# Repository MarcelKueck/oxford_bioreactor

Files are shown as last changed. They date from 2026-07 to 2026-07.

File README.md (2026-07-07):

# oxford_bioreactor

Parametric CAD for the soft hollow-fibre bioreactor chamber.

## `fusion360/end_piece_and_ring.py`

Builds one rigid **end piece** + its **tightening ring** (both Formlabs SLA, biocompatible
resin). The two chamber ends are geometrically identical, so this single part serves both —
print two end pieces and two rings.

**How to run**
1. In Fusion 360 open a new/empty **Design**, then **Utilities → Scripts and Add-Ins → Scripts → Create** a Python script and replace its `*.py` with `end_piece_and_ring.py` (or point the script folder at `fusion360/`).
2. Select it and click **Run**. It builds two components (`EndPiece`, `TighteningRing`) in the active document and pops a summary; nothing is saved or exported. Re-running is safe — it deletes and rebuilds the two components.
3. **Tweak first:** `shell_bore` (bore for the fibre bundle + potting) and `spigot_OD` (must match your silicone cuff ID); edit them under **Modify → Change Parameters** or at the top of the script, then Run again. Set `USE_LUER = False` near the top for hose barbs (`tubing_id`) instead of female Luer ports.

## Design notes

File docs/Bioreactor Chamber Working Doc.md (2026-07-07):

# Soft Hollow-Fibre Bioreactor Chamber — Project Working Document

*Personal reference and working log. Created 26 June 2026.*
*This is a living document — update the checklists, logs, and KPIs as the project moves and as numbers get locked down.*

---

## 0. How to use this

This is my single source of truth for the internship: what I'm building, why, what's been tried already, what the targets are, and what I still need to find out. Sections 1–2 are context I can re-read or lift when explaining the project. Sections 3–9 are the working core. Sections 10–12 are checklists and logs I tick off and add to as I go.

The one structural idea to keep in mind: **everything is organised around two feedback loops** (chamber design, then fibre potting), and a feedback loop is only real if the test half produces a repeatable *number*. So my first job isn't a chamber redesign — it's building the test rig that makes redesigns comparable.

---

## 1. Project at a glance

**What the project is.** I'm contributing to Marie Kruth's DPhil (NDORMS, supervised by Prof. Pierre-Alexis Mouthuy, with Profs. Philippa Hulley and Hua Ye). The DPhil is building a human *in vitro* skeletal-muscle model to reduce reliance on animal models — most drugs that work in animals fail in human trials, so there's a real need for human-relevant muscle tissue for drug testing and disease study.

**The three-part DPhil plan, and where I fit:**

1. *Electrospun hollow-fibre (eHF) scaffold* — mostly done (dissolvable collector, electrospinning, stretch-alignment). This is Marie's completed work.
2. **Soft flexible bioreactor chamber** — **this is my piece.** The chamber houses the fibre bundle, perfuses it (artificial vasculature, beating the ~100–200 µm diffusion limit), and transmits mechanical stretch to the growing tissue.
3. *Muscle culture + drug response* — downstream, depends on a working chamber.

**Why "soft."** Muscle needs cyclic mechanical loading to mature. So the chamber can't be a rigid cartridge — it has to flex to pass stretch from an external mechanical platform to the fibres, while still perfusing them.

**People & roles**
- *Marie Kruth* — supervisor, owns the DPhil, my main point of contact and the source of most of the numbers I still need.
- *Prof. Mouthuy* — PI; his group also built the humanoid bioreactor platform (Mouthuy et al., 2022, *Comms Eng*) that's a candidate mechanical-loading system.
- *Profs. Hulley & Ye* — co-supervisors.

**Timeline note.** The project proposal labels the build as Aug–Sept 2026, but I'm starting now (late June). That's actually ideal: **June–July is the natural window to build the test rigs and lock down the missing numbers**, so that when the core build phase hits I'm iterating against real, quantitative targets instead of figuring out how to measure things.

**Toolchain:** Fusion 360 (CAD) → SLA 3D printing (clear medical-grade resin) → soft membrane bonded on (Permali Tuftane TPU film, Stormsure polyurethane glue).

---

## 2. What I'm building

### The inherited starting point (one option, not a requirement)
The design I'm inheriting: two rigid SLA-printed end-pieces ("top and bottom") connected by a flexible TPU membrane sleeve in the middle. Medium perfuses through; the membrane flexes to transmit stretch; the fibre bundle runs down the axis, potted into the printed pieces at each end. **This is a valid starting point, not a constraint** — see "Architecture: what's fixed vs what's mine to decide" below.

### Current design state (from my Fusion file)
The model shows the two printed pieces. Each has:
- A main **axial bore** with a **threaded ("screwed") collar** at the connecting end.
- A **side luer-lock port**.
- **Grooves** for the membrane and elastic-ring fixation.

The threaded collars and the membrane are how the two halves join; the membrane bridges them in the assembled chamber.

### The fibres the chamber must accommodate
Post-stretch eHF specs (PVA-based, from Marie's transfer report) — these constrain the bore geometry and potting volume:
- Overall diameter ≈ **198 µm**, wall ≈ **41 µm**, lumen ≈ **89 µm**
- Working length used in potting trials: **8 cm**
- This phase: tens of fibres (potting trials ran ~10–18). **Eventual target: several hundred fibres**, potted with intact dissolvable cores then flushed simultaneously.

### The two flow circuits — RESOLVED: 2 pairs, 4 ports total
**Confirmed:** the chamber has **two independent flow circuits**, each with its own inlet and outlet → **2 inlets + 2 outlets = 4 ports.**
- **Intracapillary (ICS)** — flow *through the fibre lumens*. Natural route is **axial** (in one end, out the other), so the fibre ends must stay open to the ICS header.
- **Extracapillary (ECS)** — flow through the **shell space around the fibres**, between the end seals. Natural route is the **side ports** (in one end, out the other).

So one valid layout is: ICS inlet + outlet = the two **axial** openings (one per end); ECS inlet + outlet = the two **side** ports (one per end). That's the topology the current Fusion model already has (axial bore + one side port per piece) — so resolving to 4 ports **doesn't necessarily mean adding ports**, it confirms what each existing port is *for*.

**The consequence that matters:** the **potting is what separates ICS from ECS.** Each end's pot must seal the shell space off from the lumen header so the two circuits can't cross-leak. That makes the ICS–ECS seal (and lumen patency) central to potting, not a nice-to-have — see §6 and the patency test in §7.

### Architecture: what's fixed vs what's mine to decide
The *requirements* are fixed. The *architecture* — how I actually realise them — is my call.

**Fixed (must be met, however I build it):**
- Leakproof under the pump / pressure conditions
- Correct dimensions (accommodates the fibre bundle; specs above)
- 2 inlets + 2 outlets (independent ICS and ECS circuits)
- Fibres can be integrated (potted, patent, surviving stretch)
- Flexible enough to transmit mechanical signals + mount to a loading platform
- Easy to assemble; looks finished, not prototype-y

**Open (my design decision) — the form factor and how flex is achieved.** Candidate directions, *not* a recommendation:
- *Inherited multi-part:* rigid SLA end-pieces + bonded flexible TPU membrane (current model).
- *Monolithic single-print:* the whole chamber printed in one go, possibly in a flexible resin so flex is intrinsic — no membrane bond, no threaded joint.
- *Fully flexible:* entirely soft body.
- Hybrids of the above.

**The one fact linking this choice to the inherited problems:** in the sealing history (§5), *every* persistent leak is at a **joint** — the threaded ends, the side ports, the membrane bond. Leakproof is a hard requirement. So the architecture choice is largely a decision about **how many joints I'm willing to have, and how each one seals.** A monolithic flexible print could eliminate the threaded joint and the membrane bond entirely — potentially dissolving most of §5 — at the cost of needing a suitable flexible printable resin and rethinking potting access and sterilisation. (The potting seal and the port connections remain regardless of architecture.) That tradeoff is the thing to weigh first.

---

## 3. Requirements, must-haves & KPIs (from kickoff)

### Requirements
- **Functional** — it works.
- **Easy to assemble** — reproducible, not fiddly.
- **Looks good — not like a prototype.** A finished-looking device, not grease-and-tape.

### Must-haves
- **Two inlets + two outlets (4 ports)** — independent ICS and ECS circuits (resolved; see §2).
- **Fibres can be integrated** (potting works and survives).
- **Flexible system to transmit mechanical signals** — must integrate into a mechanical loading platform.

### KPIs (as stated — these need real numbers)
- 10,000 cycles of cyclic loading
- A certain pressure held for a certain time
- Structural integrity after a certain time in the pump system

### What each KPI actually means, and the numbers I have to get

The KPIs are the right *instincts* but under-specified, and most of the missing numbers aren't mine to invent — they come from the pump, the platform, and the culture protocol. They resolve into **three distinct tests**:

| Test | What it measures | Why "a certain X" is incomplete | Number I need |
|---|---|---|---|
| **Burst / leak pressure** | Quasi-static: pressure at which it leaks or fails | A pressure target is meaningless without the pump's working pressure to set a margin above | Pump **operating pressure** (+ flow rate) |
| **Cyclic fatigue** | Survival over 10k cycles | Cycles are meaningless without **strain amplitude + frequency**. At ~1 Hz, 10k cycles ≈ 3 h — almost certainly a **first milestone**, not the endurance bar | Strain %, frequency, and the *real* target cycle count / duration |
| **Combined endurance** | Perfusion **+** cyclic loading running together over time; catches delamination & slow leaks the other two miss | "A certain time" must be tied to how long a culture actually runs (muscle differentiation is often 1–2+ weeks) | Intended **culture duration** |

> Typical muscle stimulation lands somewhere around ~10% strain at ~0.5–1 Hz, but this varies a lot — **do not hard-code it; get the actual protocol from Marie.**

---

## 4. My operating structure: the two feedback loops

The kickoff defined two prioritised feedback loops. The dependency order is correct and worth internalising.

```
PRIORITY 1 — CHAMBER DESIGN LOOP
   design (Fusion) → SLA print → ASSEMBLE → quantitative test → iterate
                                              │
                          (leak / pressure / cyclic / endurance + mechanical attachment)

PRIORITY 2 — FIBRE POTTING LOOP
   potting protocol → pot bundle → quantitative readout → iterate
                                        │
                       (lumen patency % / alignment / ICS–ECS seal)
```

**Why P1 leads:** a chamber that won't seal or survive the pump is useless however cleanly the fibres are potted. I *can* pot into a rough chamber to test potting in isolation, but I *can't* meaningfully test sealing without a chamber design first. So P1 first, and the two loops can later run partly in parallel.

**The real first task (hiding inside P1):** a feedback loop needs a repeatable number. The lab's current leak test is qualitative — run water, watch for drops. That tells me *leaks / doesn't leak today*, not whether v3 is 20% better than v2. **So before any chamber iteration, build the test rig** (see §7). Treat "build the rig" as task 0 and the first redesign as its first input.

---

## 5. Inherited problem 1 — Sealing (the heart of Priority 1)

### The situation in one paragraph
The **membrane-to-printed-piece bond** can be made to work well. The persistent leak points are the **threaded ("screwed") end joints** and the **side luer ports**. The *only* thing that has ever fully sealed them is **vacuum grease + multiple parafilm layers** — which is impractical, fails "looks good," fails "easy to assemble," *and still leaks if pressure is pushed*. Replacing this grease-and-tape approach with a designed/glued solution is **the** central unsolved problem for P1.

### What's been tried (timeline)

| Date | Key change tested | Outcome at threaded ends & luer ports | Verdict |
|---|---|---|---|
| 26 Mar | First full assembly; PU glue + **cable ties**; luer stops on ends | Side ports wouldn't close (support-structure residue, temp-fixed with blue tac); leak at screwed ends; tape failed; parafilm reduced but dripped; **grease + parafilm → sealed** | Grease+parafilm only working seal |
| 8 Apr | Membrane → 1.8 cm; **elastic rings** instead of cable ties; side luers drilled out | Rings *block the area under the membrane* → glue can't distribute → worse bond; leaks at ends and drilled luers; grease + 2× parafilm sealed; **raised pressure → membrane–piece bond leaked** | Elastic-rings-during-cure is the wrong call |
| 23 Apr | **Cable ties during cure, removed after drying**; PTFE film on joints | PTFE alone didn't seal; grease + parafilm sealed; **raised pressure → no leak at ends or attachment** | Cable-tie-then-remove bond works under pressure ✅ |
| 8 May | **PTFE on the inside** of joints (vs outside) | PTFE only → leaks; PTFE + 1–2 parafilm → leaks; **PTFE + 3 parafilm → fully sealed under pressure** | Works but clearly impractical |

### Settled vs open
- ✅ **Settled:** Bond the membrane with **PU glue + cable-tie compression during cure, then remove the cable ties.** Use cable ties, *not* elastic rings, so glue fully wets under the membrane. This survives raised pressure.
- ❌ **Open (my design target):** the threaded joints and luer ports. Everything that seals them is grease/tape. **Direction: redesign these as integrated/glued/captured geometry** so they seal by design, not by manual sealant.

### Highest-leverage insight
The **threaded ends are also the load path** to the mechanical platform. They are simultaneously (a) the worst leak point, (b) the worst offender against "looks good" and "easy to assemble," and (c) the force-transmission interface. **Fixing the end-piece design addresses sealing, aesthetics, assembly, and mechanical attachment in one move.** This is where to spend design effort first.

---

## 6. Inherited problem 2 — Fibre potting (Priority 2)

### Goal
A fibre bundle potted into the printed piece such that: lumens stay **open** (perfusable), fibres stay **straight/aligned**, the pot **seals ICS from ECS**, the **support piece can be removed**, and the pot **survives post-potting stretching**.

### What's been tried (timeline)

| Date | Setup | Key findings |
|---|---|---|
| 24 Mar | 3 cores-removed fibres in a cut 3 mL syringe | Potting works; easy at n=3, flagged as harder at scale → *"may need a removable lid."* Viscosity is the knob: too thick won't wick between fibres; too thin → capillary flow *into* lumens |
| 8 Apr | 18 fibres, flexible sleeve + syringe injection | 8 cm length chosen; screw pieces still fit after cutting (no PU/membrane interference ✅); cross-sections ~15/18 and ~14/18 lumens open — majority patent, **but only 2 sections sampled** |
| 28 Apr | 15 fibres, membrane → 2.3 cm for alignment, cure upside-down to fight bubbles | Injection **pushes fibres sideways → curving**; **new air bubbles form during injection**; upside-down cure **failed — membrane bent under resin weight and tipped**; some resin influx into lumens |
| 28 May | 10 fibres, support structure, fibres tied both ends, 3 rings vs sagging, upside-down cure rigged straight | **Curving solved** (fixing both ends ✅); **even distribution** (no tilt ✅); **support piece still won't come out** ❌; **resin sagging persists** ❌; migration unclear |

### Open problems (what still needs solving)
- **Support-piece removal** — still impossible. Next ideas: grease the screwed part before potting; or **redesign to avoid the support entirely** (cf. the "removable lid" idea from 24 Mar).
- **Resin sagging** — persists. Next: shorten the support structure; revisit geometry/orientation.
- **Air bubbles during injection** — degassing + injection method.
- **Resin infiltration into lumens** — partly mitigated by squeezing/closing fibre ends; tune resin viscosity.
- **Resin migration along fibres** — still unclear; needs cleaner cross-section sampling to even measure.
- **Scale-up** — from ~10–18 fibres to 50–60, eventually hundreds.
- **Quantification** — currently 2 hand-counted cross-sections. Not statistically meaningful, and a prime automation target (see §7).

---

## 7. The test rigs — my engineering edge

This is the highest-value thing I bring to a lab that's been doing this **by hand**. Each loop's "test" half should output a number, logged automatically.

### Priority 1 rigs (build these first)
- **Pressure-decay / leak rig (the key one).** Seal the chamber, pressurise to a set point, close the valve, **log pressure vs time** with a pressure transducer + microcontroller (e.g. Arduino). A pressure drop = a quantified leak rate → directly comparable across designs. Cheap, fast, and turns the qualitative drip-test into a real metric.
- **Burst test.** Ramp pressure to failure, record the max. Pairs with the pump operating pressure to set a safety margin.
- **Cyclic loading rig.** Mount the chamber on a linear actuator (or the lab's uniaxial stage), cycle at the agreed strain/frequency, **count cycles automatically**, and run a pressure-decay check at intervals (e.g. every N cycles) to track degradation.
- **Combined endurance.** Chamber in the pump loop *and* on the cyclic rig, run for the target duration with continuous pressure logging; watch for membrane-bond delamination and slow leaks.

### Priority 2 readouts
- **Automated lumen counting.** Replace manual cross-section counting with image analysis (Fiji/ImageJ like Marie, or a Python/OpenCV script) to count open vs blocked lumens and measure alignment across *many* sections → a real patency %.
- **Fluid-passage / patency test.** Perfuse through the potted bundle, measure flow/pressure, confirm lumens are patent **and** the pot seals ICS from ECS.

> Building these rigs is also the most defensible "concrete, demonstrable result" to point to at the end of the summer — a measurement system the lab keeps using.

---

## 8. External inputs I must lock down (ask Marie / Mouthuy early)

These constrain the design more than anything in the requirements list. Get them before committing to geometry.

- [ ] **Pump operating pressure + flow rate** → sets pressure/burst test targets.
- [ ] **Mechanical platform interface** — mounting geometry, **stroke/displacement range**, frequency capability (uniaxial stage and/or the humanoid platform, Mouthuy 2022). This dictates the end-piece design.
- [ ] **Stimulation protocol** — strain %, frequency, target duration → sets the cyclic-fatigue KPI.
- [ ] **Culture duration** → sets the combined-endurance test duration.
- [ ] **Sterilisation method** (autoclave vs other) → affects resin and membrane material choice; confirm the current materials survive it.
- [x] **Inlet/outlet count — RESOLVED:** 2 pairs = 4 ports (independent ICS + ECS). See §2 and decision log.
- [ ] **Fibre-count target for this phase** (tens now → hundreds later) → bore size and potting volume.

---

## 9. Parked for later — but design so I don't foreclose them

From the "later with Marie" discussion. Don't build these now; just don't make them impossible.

- **Electrical stimulation.** Connects to the conductive PEDOT:PSS already in the fibre pipeline. **Leaving room for electrode ports costs nothing now** — keep it in mind when laying out the end-pieces.
- **Functional readout via pillars sensing displacement.** The classic muscle-on-flexible-posts force measurement: pillars deflect, you track displacement → contractile force. Displacement tracking is a **vision/sensing problem — squarely my territory**, and the most interesting potential demonstrable result. But it depends on a working, sealed chamber first.

> Keep both firmly in "later." Do **not** let them pull focus from Priority 1.

---

## 10. Formal design-criteria checklist

From `Design_criteria.docx`. Tick as each is met and verified by a test.

**Casing**
- [ ] Improved architecture via CAD + prototyping
- [ ] Integrates into an external mechanical loading system
- [ ] Transmits force from the loading system
- [ ] Easy chamber assembly
- [ ] Independent inlet/outlet pathways per compartment (intracapillary + extracapillary)
- [ ] Structural integrity during mechanical loading
- [ ] Leak-free operation + uniform flow during perfusion
- [ ] Sufficient space/geometry for potting and sealing

**Fibre potting**
- [ ] Reproducible potting workflow
- [ ] Easy incorporation of fibres into the casing
- [ ] Clean, consistent results
- [ ] Limited fibre curving + even resin distribution
- [ ] No resin infiltration into / migration along fibres
- [ ] Compatible with post-potting stretching
- [ ] Structural integrity during perfusion

---

## 11. Open questions & decisions log

**Open questions** (move to the decision log once resolved):
- Real cyclic target (strain / frequency / cycle count)?
- Sterilisation method and material compatibility?
- Architecture: multi-part + membrane vs monolithic flexible print vs fully flexible?
- Is the support structure kept (and made removable) or designed out entirely?

**Decision log**

| Date | Decision | Rationale |
|---|---|---|
| 26 Jun 2026 | Chamber uses **2 flow circuits = 4 ports** (2 in, 2 out): ICS through the fibre lumens (axial), ECS through the shell space (side). | Standard dual-circuit HF-bioreactor design; matches the design-criteria requirement for independent pathways per compartment. Implementation / form factor deliberately left open. |
| | | |

---

## 12. Progress log

| Week / date | Focus | Done | Blockers | Next |
|---|---|---|---|---|
| Jun–Jul (ramp-up) | Build P1 test rig(s); lock down §8 numbers | | | |
| | | | | |

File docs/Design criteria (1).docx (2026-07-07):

Marcel’s Project – Design Criteria for Bioreactor Chamber

1. Redesigning the Casing

- Improve the architecture of the bioreactor casing through computer-aided design and prototyping.
- The design should allow for integration into external mechanical loading systems.
- The design should allow for force transmission from mechanical loading systems.
- The design should enable easy chamber assembly.
- The design should enable independent inlet/outlet pathways for each compartment where flow can occur both inside fibers (intracapillary flow) and in the surrounding space (extracapillary flow) (Eghbali et al., 2016).
- Ensure structural integrity during mechanical loading.
- Ensure leak-free operation and uniform flow during perfusion.
- Ensure sufficient space and geometry for fiber potting and sealing.

2. Fiber Potting

- Develop a reproducible assembly workflow for fiber potting.
- Use computer-aided design and prototyping to improve the potting design.
- The workflow should allow for easy incorporation of fibers into the bioreactor casing.
- The workflow should allow for clean, consistent results.
- Ensure limited fiber curving and even resin distribution.
- Avoid resin infiltration into fibers and resin migration along fibers.
- Ensure design compatibility with post-potting fiber stretching.
- Ensure structural integrity during fiber perfusion.

Papers

Nie, M. et al. (2025) ‘Scalable tissue biofabrication via perfusable hollow fiber arrays for cultured meat applications’, Trends in Biotechnology, 43(8), pp. 1938–1960. doi:10.1016/j.tibtech.2025.02.022.

Hou, Y. et al. (2022) ‘The application of hollow fiber cartridge in biomedicine’, Pharmaceutics, 14(7), p. 1485. doi:10.3390/pharmaceutics14071485.

Diban, N. and Stamatialis, D. (2014) ‘Polymeric hollow fiber membranes for bioartificial organs and tissue engineering applications’, Journal of Chemical Technology &amp; Biotechnology, 89(5), pp. 633–643. doi:10.1002/jctb.4300.

Eghbali, H. et al. (2016) ‘Hollow fiber bioreactor technology for tissue engineering applications’, The International Journal of Artificial Organs, 39(1), pp. 1–15. doi:10.5301/ijao.5000466.

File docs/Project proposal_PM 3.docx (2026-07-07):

Project summary – Marcel – Aug-Sept 2026

Development of a soft hollow fibre bioreactor for muscle Tissue Engineering

Project Summary

This summer project focuses on the design and assembly of a soft, flexible bioreactor chamber to support skeletal muscle tissue engineering using electrospun hollow fiber scaffolds. The system will be developed as part of a broader DPhil project that investigates the application of electrospun hollow fibers for the development of a skeletal muscle drug testing platform.

Hollow fiber bioreactors are widely used to mimic native vasculature to enable efficient delivery of oxygen and nutrients and removal of metabolic waste by overcoming diffusion limits that restrict tissue thickness in static cultures (Eghbali et al., 2016). Recent advances demonstrate that densely packed, perfused hollow fiber arrays can support centimeter-scale muscle tissue formation with improved structural and functional maturation (Nie et al, 2025).

In this project, you will contribute to the design of soft chamber enabling dual perfusion and mechanical stimulation, both of which are critical for muscle tissue development.

Project Objectives

- Understand the design concept of a flexible chamber (see Marie’s transfer report) that can accommodate electrospun hollow fibers.
- Improve the existing concept to enable clean, easy and consistent manufacture. The design should ensure sufficient space and geometry for fiber potting and sealing and confirm structural integrity and leak-free operation. It should also allow for force transmission from mechanical loading systems.
- Ensure the chamber can be integrated into an external mechanical stimulation system (e.g., stretching or cyclic loading).

Methods

Prototype the chamber using the Fusion 360 design software, stereolithography 3D printing, and gluing of a soft membrane.

Relevant Papers

Nie, M. et al. (2025) ‘Scalable tissue biofabrication via perfusable hollow fiber arrays for cultured meat applications’, Trends in Biotechnology, 43(8), pp. 1938–1960. doi:10.1016/j.tibtech.2025.02.022.

Hou, Y. et al. (2022) ‘The application of hollow fiber cartridge in biomedicine’, Pharmaceutics, 14(7), p. 1485. doi:10.3390/pharmaceutics14071485.

Diban, N. and Stamatialis, D. (2014) ‘Polymeric hollow fiber membranes for bioartificial organs and tissue engineering applications’, Journal of Chemical Technology &amp; Biotechnology, 89(5), pp. 633–643. doi:10.1002/jctb.4300.

Eghbali, H. et al. (2016) ‘Hollow fiber bioreactor technology for tissue engineering applications’, The International Journal of Artificial Organs, 39(1), pp. 1–15. doi:10.5301/ijao.5000466.

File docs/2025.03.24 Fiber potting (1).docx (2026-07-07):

24th Mar 2025

Testing potting of electrospun hollow fibers

Overview:

- eHFs need to be potted into the bioreactor chamber
- Fiber potting will be tested in pre-cut 3mL syringes

Procedure:

- Cut the ends of a 3mL syringe
- Prepare three fibers without core
- Place the fibers inside the syringe
- Add polyurethan resin (P.U. Glue)
- Let the resin cure for min. 12 hours
- Cut the fibers and check for an open fiber lumen

Notes:

- If the resin is too viscous, it will not reach between the fibers
- If the resin is not viscous enough, the capillary effect will cause it to flow into the fibers

Results:

- Potting of fibers without core worked well
- Ease/Practicality of potting (important for scale-up): Easy for three fibers. Might become more challenging large amounts of fibers. May require a removable lid to assist fiber potting
- Material compatibility with PCL: No effects on PCL were noted
- Fiber contamination (Material traveling beyond the potting area): No material noted inside fibers. Need to cut closer to the potting area for further analysis
- Ease of cutting: Fibers were cut outside the resin area. Need to identify feasibility of this when large numbers of fibers are potted

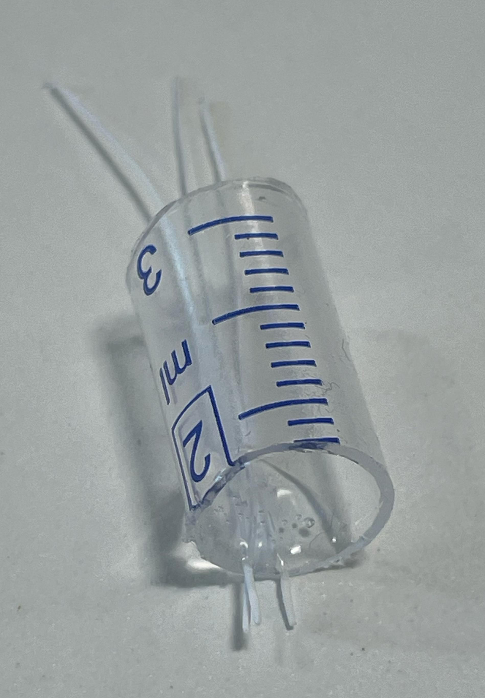
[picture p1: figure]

Next steps:

- A different resin will be tested
- Potting with larger numbers of fibers needs to be tested
- Leakage needs to be analyzed
- Biocompatibility needs to be tested

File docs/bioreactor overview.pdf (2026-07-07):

# Soft Hollow-Fibre Bioreactor — final assembly

Simplified schematic. Axis runs left→right; the chamber is shown cut open.

Rigid end-piece (BioMed Clear) | Flexible middle (Flex 80A) | Potting (PU) | O-ring | ICS (in lumens) | ECS (shell)

ICS in
ICS out
ECS in | ECS out

flexes to stretch the tissue

Flexible middle — one piece
thick connectors + thin flexing wall
O-ring joint
seals + retains

Rigid end-piece
(BioMed Clear)

Potting (PU)
anchors fibres · seals ICS↔ECS

eHF hollow-fibre bundle

## What it's made of — exploded

Rigid end-piece A | O-ring | Flexible middle — printed in one piece | O-ring | Rigid end-piece B

eHF bundle — threaded through all three parts, potted into each rigid end

Parts: 2 rigid end-pieces · 1 flexible middle (one print) · 2 O-rings · 1 fibre bundle

## The joint — why it won't leak under cyclic pull

fibres pass through bore

O-ring, radial gland → seals pressure

rib + groove → carries the pull (the load path)

Flexible socket (Flex 80A)

Rigid spigot (BioMed Clear)

Sealing and load-bearing are handled by separate features — so cyclic tension can't walk the seal out.

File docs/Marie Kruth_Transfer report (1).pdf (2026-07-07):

## Electrospun hollow fibres for muscle tissue engineering in a soft bioreactor chamber

DPhil Transfer Report

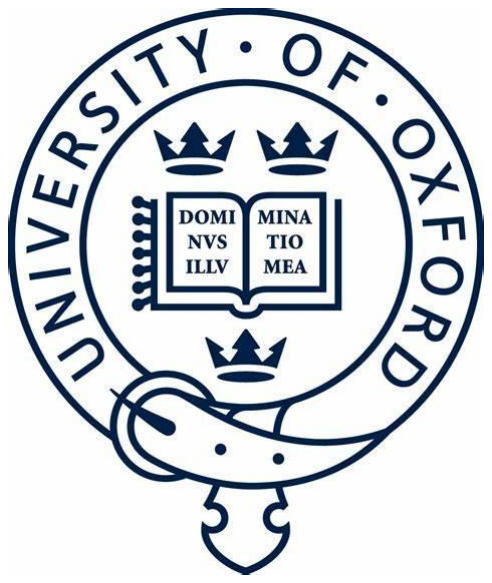
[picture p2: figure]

## Marie Beatrix Kruth

St. Peter’s College
University of Oxford

Supervised by
Prof. Pierre-Alexis Mouthuy Prof. Philippa Hulley
Prof. Hua (Cathy) Ye

Submitted: Michaelmas 2024

This document is submitted to the Nuffield Department of Orthopaedics, Rheumatology, and Musculoskeletal Sciences (NDORMS) for the Transfer of Status requirement.

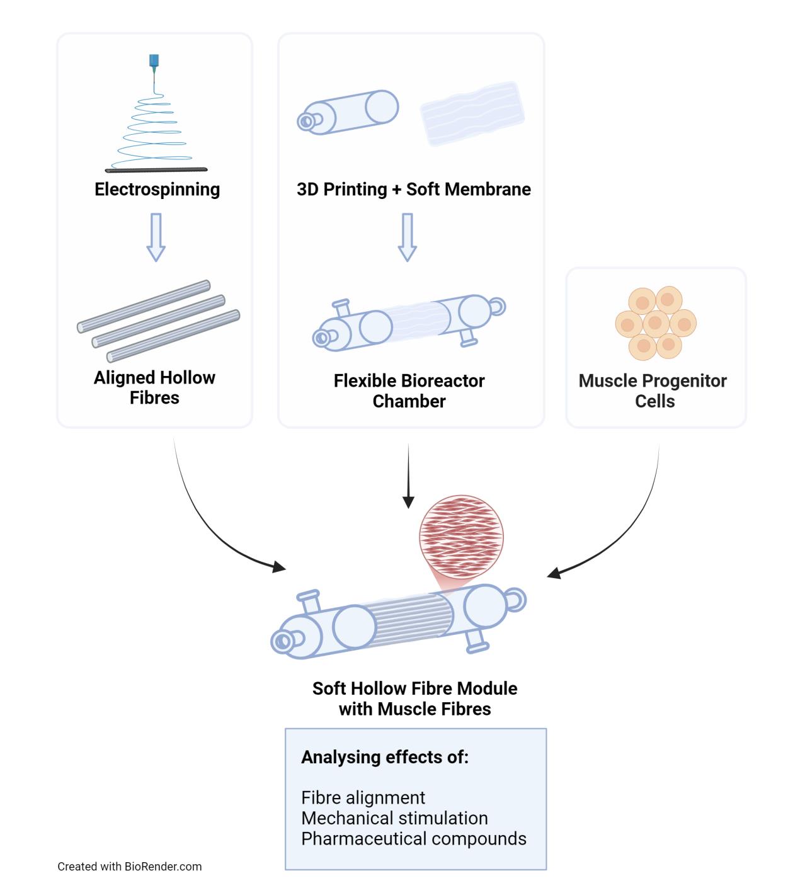
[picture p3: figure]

Abbreviations
dECM | Decellularized Extracellular Matrix
DMSO | Dimethyl Sulfoxide
ECM | Extracellular Matrix
eHFs | Electrospun Hollow Fibres
Fmax | Maximum Force
HFs | Hollow Fibres
HFIP | Hexafluoroisopropanol
MHC | Myosin Heavy Chain
micro-CT | Micro-Computed Tomography
MSK | Musculoskeletal
Mw | Molecular Weight
myoD | Myoblast Determination Protein 1,
PCL | Polycaprolactone
PDO | Polydioxanone
PEDOT:PSS | Poly(3,4-ethylenedioxythiophene):Poly(styrenesulfonate)
PVA | Polyvinyl Alcohol
qPCR | Quantitative Polymerase Chain Reaction
RT | Room Temperature

List of Figures
Figure 1 | Structure of skeletal muscle | p.1
Figure 2 | Hollow fibre bioreactor platforms | p.3
Figure 3 | Production of the dissolvable fibre collector | p.5
Figure 4 | Production of electrospun hollow fibres | p.6
Figure 5 | Tensile mechanical properties of the dissolvable fibre collector | p.7
Figure 6 | Effects of PEDOT:PSS and PVA concentrations on electrical resistance and extrusion length | p.8
Figure 7 | Characterisation of pre- and post-heating fibre collectors made from different PVA types | p.9
Figure 8 | Dimensions of pre- and post-stretch electrospun hollow fibres | p.11
Figure 9 | Diameter and alignment of pre- and post-stretch electrospun microfibres p.12

## Table of Contents

# 1. Background

## 1.1 Skeletal Muscle Research

Skeletal muscle makes up 40% of human body mass and serves as the engine for movement and force generated through its contractile functions [1]. This tissue has a hierarchically structured architecture made up of bundles of muscle fascicles which consist of muscle fibres that are in turn composed of bundles of myofibrils [2] (Fig. 1). Muscle fibres can reach diameters of up to 100μm and lengths of up to 30 cm [3], and the tissue possesses remarkable regenerative capacities due to its resident satellite cells [4].

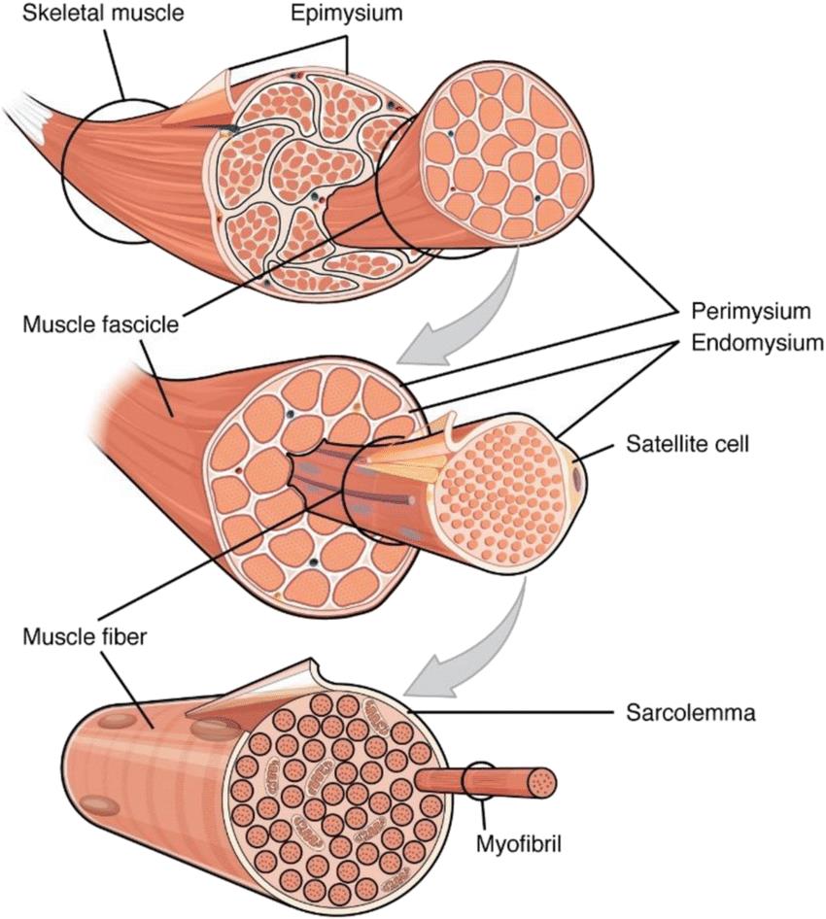
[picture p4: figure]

Fig. 1: Structure of skeletal muscle Hierarchical structure showing bundles of muscle fascicles, muscle fibre and myofibrils [2]. Worldwide, musculoskeletal (MSK) conditions contribute to a significant global burden, with around 1.71 billion cases [5]. A subset of these conditions includes a wide spectrum of skeletal muscle diseases which contribute to pain and impairment of mobility, strength and function. This includes acquired disease forms, e.g. sarcopenia, as well as congenital forms, e.g. muscular dystrophy [6], [7]. Animal models have been extensively used in the study of the MSK system, including skeletal muscle. In the EU, over 70,000 animals are used annually for basic research on the MSK system in addition to over 48,000 animals used for translational and applied research on MSK disorders [8].
The use of animal models in MSK research is associated with major limitations, including reproducibility issues, ethical concerns, and limited relevance to human physiology. Reproducibility issues result from the complexity of animals as physiological systems, which can interfere with the replicability of experimental results [9]. Ethical concerns arise from the fact that animals may be subjected to different procedures which induce physical harm and cause severe pain, discomfort, and distress [10].
Importantly, animal models can be highly unreliable in the prediction of human responses due to interspecies variation relating to physiology, metabolism, and genetic makeup. Thus, animal studies often do not translate to human use due to physiological differences, limiting their relevance and applicability [11]. Drug testing is particularly impacted by this, as most drugs identified to work in animals fail to translate to humans, with 89% of new drugs failing when entering clinical trials [11]. Taken together, this creates an urgent need for alternative models in muscle research with enhanced reliability and human relevance.

## 1.2 Skeletal muscle tissue engineering

Muscle tissue engineering holds great promise for the development of human in vitro models that could replace animals in research with numerous potential applications for drug development, drug screening, and the study of developmental or pathophysiological processes. Such models can, for example, be used to test novel pharmaceutical compounds prior to introducing them in humans to identify potential toxicities and determine efficacy in a human-relevant system. Despite the significant potential, the development of constructs that accurately mimic the complexity and heterogeneity of native tissues still presents a challenge today, which limits their clinical applicability and widespread adoption. One of the key challenges is the diffusion limit which impedes gas and nutrient exchange in thicker engineered tissues. Specifically, muscle has high metabolic demands and strongly depends on an efficient supply of oxygen and nutrients. Gases and nutrients can typically reach depths of 100-200µm by passive diffusion [12], with cells beyond this point undergo necrotic cell death. This largely restricts the size of in vitro tissues which limits their functionality and clinical applicability.
Another limiting factor is a lack of appropriate mechanical stimulation to support tissue development. Muscle tissue relies on mechanical input for growth and maturation as a highly dynamic tissue that undergoes cyclic loading and unloading during contraction and relaxation. Inside the body, different mechanical stresses act upon the tissue from multiple axes, which largely contributes to its effective development [13], [14]; however, traditional tissue engineering approaches insufficiently mimic the required mechanical stresses.

## 1.3 Hollow fibre bioreactor platforms

Hollow fibre (HF) bioreactors are used in tissue engineering and promise three-dimensional tissue culture with enhanced nutrient and oxygen transport (Fig. 2A). These modules contain semi-permeable HFs that provide a scaffold for growing tissue and mimic the function of the vasculature [15] (Fig. 2B). While providing enhanced nutrient and gas exchange, implementing HF modules that are soft and flexible could additionally enable mechanical stimulation through force transmission within a dynamic bioreactor system.
HFs are typically produced through extrusion, leading to smooth and stiff fibres that are not adapted to cell culture (Fig. 2C,D). Electrospun HFs (eHFs), on the other hand, are made up of microfibres and can be implemented to generate a flexible porous scaffold membrane for effective mechanical force transmission and diffusive exchange with the surrounding environment (Fig. 2E,F). Additionally, eHFs provide topographical stimuli, as their microfibres mimic the extracellular matrix (ECM) that surrounds cells inside the body to provide anchorage, structural signalling, and guidance cues [16], [17]. While eHF bioreactors show considerable promise, their scalability and functionality has yet to be demonstrated.

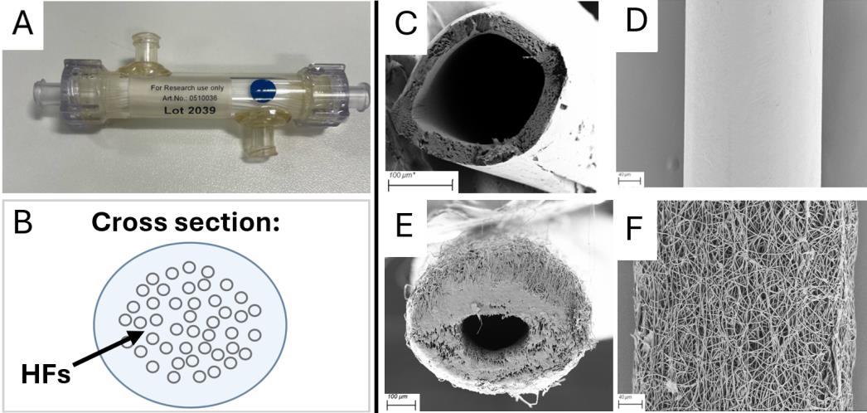
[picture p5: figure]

Fig. 2: Hollow fibre bioreactor platforms
A. Hollow fibre (HF) bioreactor module from AlphaPlan, B. Cross section of a HF bioreactor module (created with BioRender), C. Cross-sectional scanning electron microscopy (SEM) image of a commercial HF taken from the AlphaPlan bioreactor module, Scale bar: 100µm, D. Commercial HF imaged from above, Scale bar: 40µm, E. Cross-sectional SEM image of an electrospun hollow fibre (eHF), Scale bar: 100µm, F. eHF imaged from above with visible microfibres, Scale bar: 40µm.

## 1.4 Research objectives

The aim of this project is to develop a novel in vitro model of human skeletal muscle with enhanced physiological relevance and applicability in research and preclinical drug screening. By integrating the use of electrospun fibres, HF bioreactors, and dynamic platforms, key challenges in muscle tissue engineering, i.e. nutrient diffusion and mechanical stimulation, will be addressed. The experimental plan will involve 1. development of an eHF scaffold, 2. development of a soft flexible eHF bioreactor chamber, and 3. analysis of the effects of mechanical stimulation and pharmaceutical compounds on cultured muscle tissue. Objective 1: Developing an electrospun hollow fibre scaffold
The eHFs made of polycaprolactone (PCL) and polydioxanone (PDO) will be produced based on previous work [18]. In that work, a stainless-steel wire was used as a collector during electrospinning to generate eHFs. This required manual removal of individual wires post-spinning. For enhanced scalability and to facilitate integration of eHFs into the bioreactor chamber, the production and application of a dissolvable fibre collector will be investigated in this project. Based on this approach, hundreds of fibres could be embedded within the bioreactor chamber and the collector cores could be dissolved simultaneously.
The first challenge in this objective will be to develop a fibre collector with the following requirements:
- Conductive (max. 150MOhm resistance)
- Dissolvable
- Force-resistant
- Diameter: ~200µm
The second challenge will be to produce the eHFs with the following characteristics:
- Microfibre diameter: 0.5-1µm
- Wall thickness: 50µm

- Aligned topography
The desired microfibre thickness is 0.5-1µm given that collagen fibrils, which are highly abundant in skeletal muscle ECM, exhibit a diameter of up to 0.5µm [19]. Previous studies additionally found that electrospun microfibres with a diameter of ~1µm provide topographical cues promote cell alignment [20]. A wall thickness of ~50µm is targeted to facilitate efficient gas and nutrient exchange while maintaining technical feasibility. For reference, the endothelium of human capillaries is up to 10µm thick [21]. Microfibres will be aligned through stretching of the eHFs to incorporate topographical guidance which is known to support differentiation of myoblasts into myofibres [22].
Objective 2: Developing a soft flexible eHF bioreactor chamber
A soft flexible bioreactor chamber will be designed to provide synthetic vascularisation and transmission of mechanical signals. The eHF scaffold will be integrated into the chamber by fibre potting. Various analyses will be applied to ensure biocompatibility, efficient medium flow, and chamber and scaffold integrity under mechanical loading. More details can be found in the ‘Future Work’ section.
Objective 3: Applying the eHF bioreactor in skeletal muscle research
Myoblasts will be seeded onto the eHFs inside the bioreactor chamber. Myogenesis will be induced, and the effects of mechanical loading will be investigated based on morphological features, protein expression, and functionality of the developed tissue. Additionally, the muscle’s preliminary utility for drug testing will be assessed. More details can be found in the ‘Future Work’ section.

# 2. Materials and Methods

## 2.1 Fabrication of a dissolvable fibre collector

A protocol for a dissolvable electrospinning collector was established. The collector was synthesized using poly(vinyl alcohol) (PVA) as the base material, dimethyl sulfoxide (DMSO), and poly(3,4-ethylenedioxythiophene) polystyrene sulfonate (PEDOT:PSS) to provide conductive properties (Fig. 3D). PVA from three different source was tested: eSUN 14kDa Mw (3D Filament eSUN), Sigma 13-23kDaMw (363170 Sigma Aldrich), Sigma 31-50kDaMw (363073 Sigma Aldrich) (Fig. 3A,B,C). PVA was dissolved in water using sonication, and DMSO (D2650 Sigma Aldrich) and PEDOT:PSS (655201 Sigma Aldrich) were added to the solution. The resulting mixture was heated (95°C) under constant mechanical stirring (300rpm) to evaporate water. The mixture was then transferred to a syringe and extruded into a curing bath of ethanol absolute (UN1170 Sigma Aldrich) (Fig. 3E). A stainless-steel dispensing tip was used with an inner diameter of either 233µm (MT30-PBN Adhesive Dispensing Ltd) or 335nm (MT27-PBN Adhesive Dispensing Ltd). The resulting dissolvable fibre collector was collected and left overnight to allow for evaporation of ethanol and water. Some of the produced collectors were exposed to heat treatment at 37°C for 2 hours.

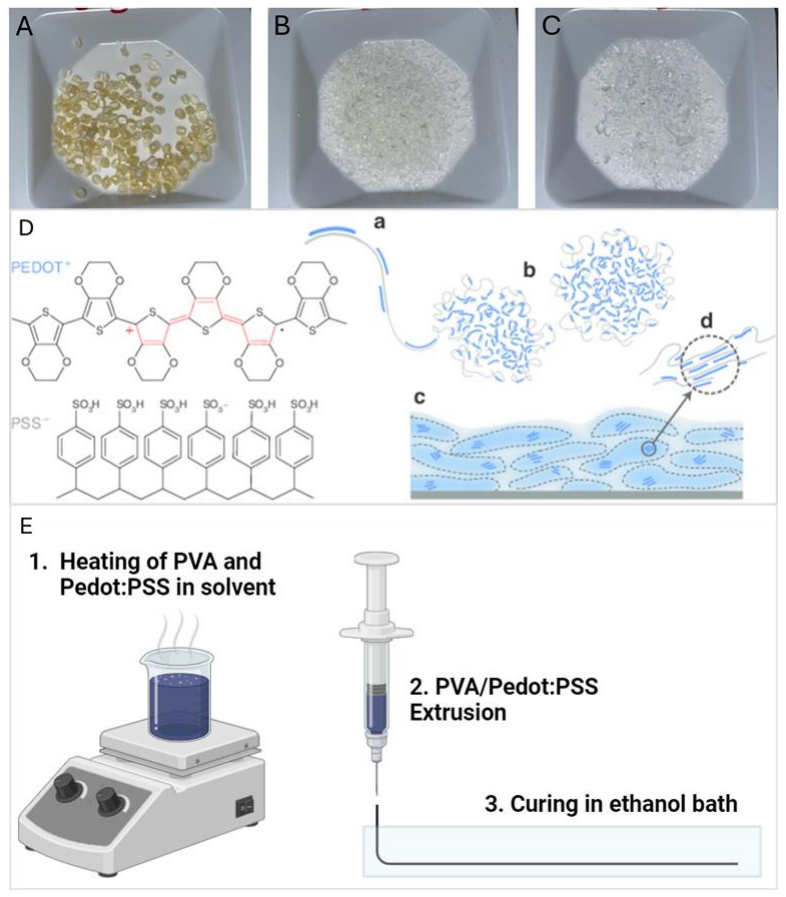
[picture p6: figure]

Fig. 3: Production of the dissolvable fibre collector
A. eSUN PVA filaments with 14kDa Mw, B. Sigma PVA crystals with 13-23kDa Mw, C. Sigma PVA crystals with 31-50kDa Mw, D. Molecular structure of PEDOT:PSS with PEDOT⁺ core and PSS⁻ shells [23], E. Schematic of the production of the dissolvable fibre collector (created with BioRender).

## 2.2 Characterisation of the dissolvable fibre collector

Conductivity of the fibre collector was determined based on resistance measurements of 10cm long collector sections using a Keithley 2400 Source Meter. Dissolvability was tested using 20cm long sections in 40mL water under constant stirring (240rpm) at room temperature (RT). Uniaxial tensile mechanical properties were tested using a ZwickRoell tensile tester (KAP-TC) with testXpert II at a speed of 10mm/min.

## 2.3 Fabrication of electrospun hollow fibres

Electrospinning solutions were prepared by mixing pyridine (110-86-1 Emsure Sigma Aldrich) into Hexafluoroisopropanol (HFIP; UN2922 Halocarbon) at a concentration of 50ppm. Polycaprolactone (PCL; Viatel C18E Ashland) and polydioxanone (PDO; RPM0400 Riverpoint Medical) were added to the HFIP/pyridine mixture at a ratio of 0.43:1 PCL to PDO, with resulting concentrations of 4.8% PCL and 11.1% PDO and a total polymer concentration (i.e. PCL+PDO) of 15.9%.
Electrospinning was performed using a rotating collector, where either a 200µm stainless-steel wire (SS316 The Crazy Wire Company) or the dissolvable fibre collector were used. The polymer solution was extruded at a speed of 0.8mL/hr with a distance of 19cm between tubing outlet and collector. Collector rotation was set to 75rpm, and varying draw speeds of either 1mm/s, 1.5mm/s, or 2mm/s were used. A voltage of 9kV was applied. Following electrospinning, samples were stored overnight to allow for evaporation of residual HFIP. The stainless-steel wire was removed by manual pulling following soaking in 70% ethanol. The dissolvable collector was removed by pre-soaking in water at either RT or 37°C and subsequent five 5-minute sonication runs (7.5MJ, 40% amp) in water.

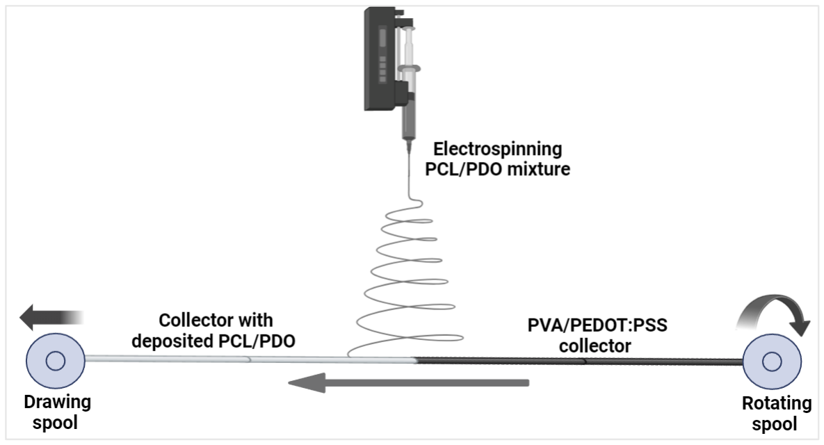
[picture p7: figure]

Fig. 4: Production of electrospun hollow fibres
The collector is drawn by a spool on the left and rotation is exerted by a spool on the right. PCL/PDO is electrospun and deposited onto the collector. Following electrospinning, the dissolvable core is removed, and the hollow fibres are stretched (created with BioRender).

## 2.4 Characterisation of electrospun hollow fibres

Light microscopy was used to determine the inner diameter, outer diameter, and wall thickness of eHFs and to detect potential changes in the fibre collector diameter as a result of plastic deformation sustained during electrospinning. Samples were imaged using ZEN Pro connected to an Olympus BX40 microscope with x10 magnification. Scanning electron microscopy (SEM) was used to assess eHF microfibre diameter and alignment. Samples were prepared with a Quorum sputter coater (Q150R ES) using QT Timed Gold at 20mA and 120s and imaged using Zeiss SmartSEM connected to a Zeiss scanning electron microscope (Sigma 300 FEG) with 80x, 220x, and 4.33kx magnification. Commercial HFs (AlphaPlan 0510036) composed of polymethylpentene with an inner diameter of 180um, an outer diameter of 260µm, and a wall thickness of 80µm were used as a control.

## 2.5 Image analysis

Light microscopy and SEM images were analysed using Fiji ImageJ. Measurements of fibre collectors and eHFs were obtained using the distance measurement tool. The total diameter, wall thickness, and lumen diameter of eHFs were calculated based on detected inner and outer diameters. Measurements of microfibre diameters were obtained using the distance measurement tool. Microfibre alignment was assessed using the Fiji Directionality plugin. The derived data was used for quantitative analyses. Statistical significance is given as P ≤ 0.05 (*), P ≤ 0.01 (**), P ≤ 0.001 (***), and P ≤ 0.0001 (****).

# 3. Results and Discussion

## 3.1 Production of a dissolvable fibre collector

### 3.1.1 Effects of PVA concentration on wet-spinning and mechanical properties

PVA serves as the base material of the dissolvable fibre collector, and its concentration plays a crucial role in efficient extrusion and curing during wet-spinning. Early experiments focused on the use of PVA Only without PEDOT:PSS and, based on a curing test (Fig. S1), an initial range of 44-65%(w/v) PVA was selected for extrusion testing. The extrusion tests revealed that concentrations above 58% were too viscous to be extruded while concentrations below 50% led to discontinuous extrusion and adhesivity of the cured product. The introduction of PEDOT:PSS into the PVA solutions resulted in increased viscosities of the mixtures, thus favouring extrusion with PVA concentrations below 52%. Notably, it was observed that higher PEDOT:PSS concentrations necessitated lower PVA concentrations in order to maintain efficient extrusion and curing.
The mechanical properties of fibre collectors made from either PVA Only or PVA/PEDOT:PSS at PVA concentrations within the range of 50-58% were tested for comparison (Fig. 5A,B). Force-displacement curves showed a significantly lower travel distance for PVA Only , indicating lower levels of plastic deformation compared to PVA/PEDOT:PSS collectors; though, no significant difference could be detected in the maximum force sustained by the different collectors (Fig. 5C).

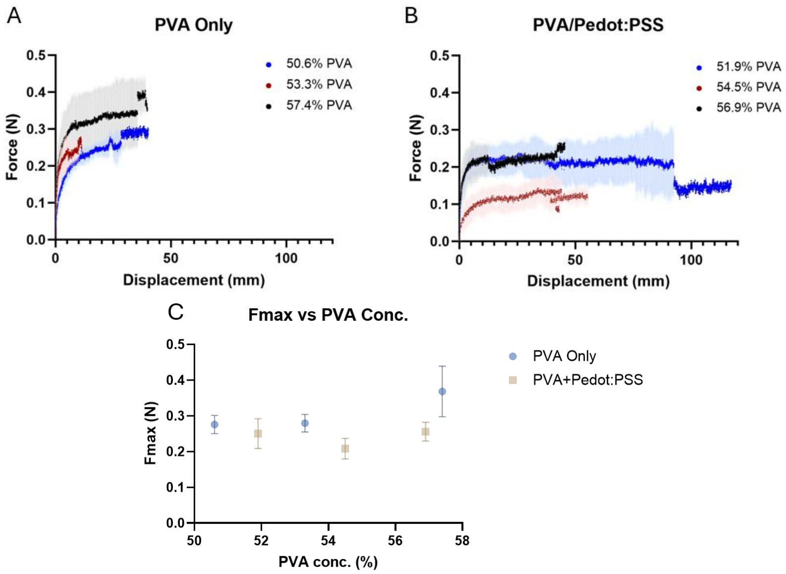
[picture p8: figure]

Fig. 5: Tensile mechanical properties of the dissolvable fibre collector
A. Force-displacement curve of PVA Only collectors with different PVA concentrations, B. Force-displacement curve of dissolvable PVA/PEDOT:PSS collectors with different PVA concentrations, C. Fmax
(N) over PVA concentration (%) of PVA Only and PVA/PEDOT:PSS collectors.

### 3.1.2 Achieving electrical conductivity and large extrusion length

Electrical conductivity of the fibre collector was crucial to enable the electrospinning process, as it must be grounded to attract electrospun fibres. The collector's conductivity is largely governed by the ratio of PEDOT:PSS-to-PVA content. Initial attempts using a PEDOT:PSS-to-PVA ratio of 4:96 yielded fibre collectors for which electrical resistance lay above the equipment’s upper limit (200MOhm), suggesting poor conductivity. The PEDOT:PSS content was therefore increased, and ratios of 9:91 and 16:84 led to average resistances of 61±10MOhm and 36±9MOhm, respectively (Fig. 6A). Considering the costs associated with PEDOT:PSS, the lowest ratio (9:91) was selected for subsequent experiments to optimise for economic feasibility and scalability. The produced collectors were then tested in the electrospinner, and deposition of electrospun fibres was observed, which proved adequate levels of conductivity.
To ensure sufficient extrusion lengths, the PVA concentration for the 9:91 ratio had to be refined, and ~41% PVA allowed for the best outcomes (Fig. 6B). The final protocol was tested and confirmed to allow for the reproducible production of fibre collectors by applying a 9:91 PEDOT:PSS-to-PVA ratio with 41% PVA and 4.1% PEDOT:PSS.

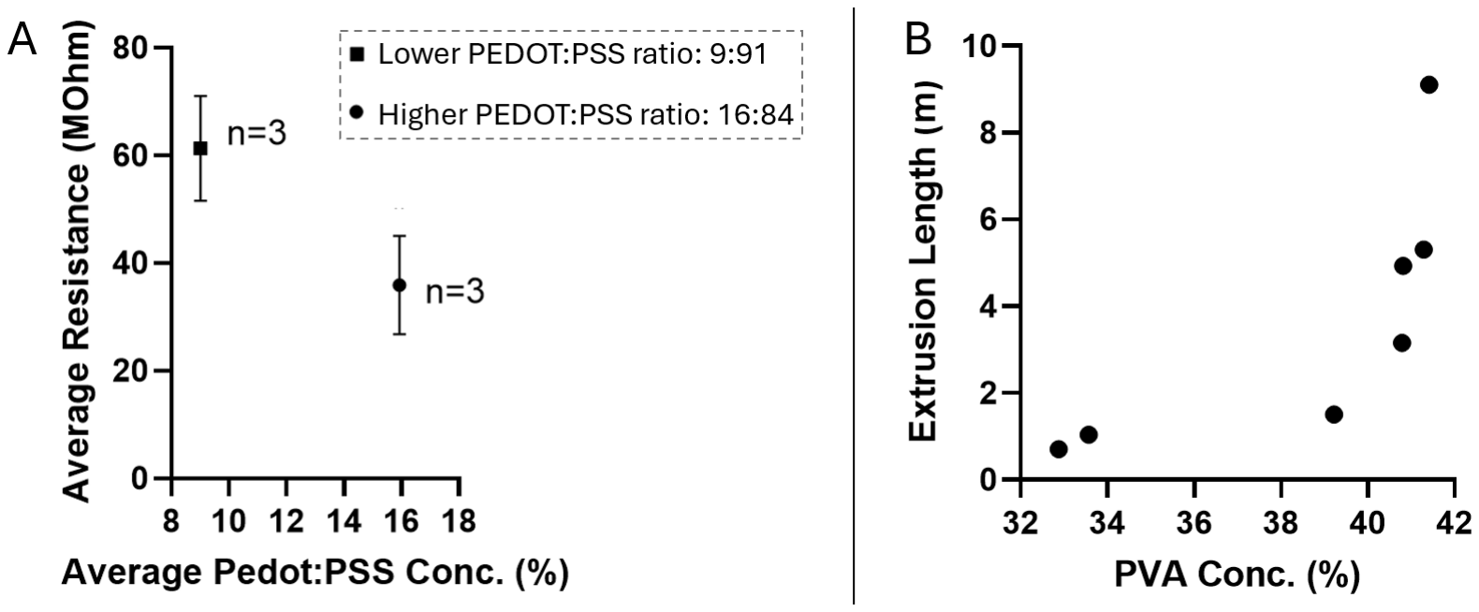
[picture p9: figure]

Fig. 6: Effects of PEDOT:PSS and PVA concentrations on electrical resistance and extrusion length
A. Average resistance of dissolvable fibre collectors with PEDOT:PSS to PVA ratios of 16:84 and 9:91, B. Extrusion length (m) over PVA concentration (%).

### 3.1.3 Effects of PVA type and heating on fibre collector properties

Three types of PVA were tested for the production of fibre collectors, including PVA with average molecular weights (Mw) of 14kDa, 18kDa, and 41kDa. All collectors were produced with a PEDOT:PSS-to-PVA ratio of 9:91. Heat treatment (30ºC, 2hrs) was applied to identify whether the collectors’ strength could be increased.
Tensile tests were conducted to compare pre- and post-heating collectors made from different PVA types. The force displacement curves revealed reduced plastic deformation of 14kDa and 18kDa fibre collectors following heating while 41kDa collectors maintained their range (Fig. 7A,B). Heating did not significantly affect the maximum force (Fmax) of the collectors; however, 41kDa collectors showed a significantly higher Fmax than their 14kDa and 18kDa counterparts

(Fig. 7C). Post-heating 41kDa fibre collectors exhibited the highest force resistance. Electrical resistance was found to be lower for 14kDa samples compared to 18kDa and 41kDa ones (Fig. 7D), and heat treatment caused a significant increase in resistance, such that conductivity could not be detected for some sections of the 18kDa and 41kDa collectors. 14kDa samples maintained the lowest average resistance, measuring 59±20MOhm pre-heating and 118±40MOhm post-heating. Notably, the dissolvability test showed no significant differences between pre- or post-heating samples made from different PVA types, as all collectors dissolved effectively after six minutes of continuous stirring in water (Fig. S3).

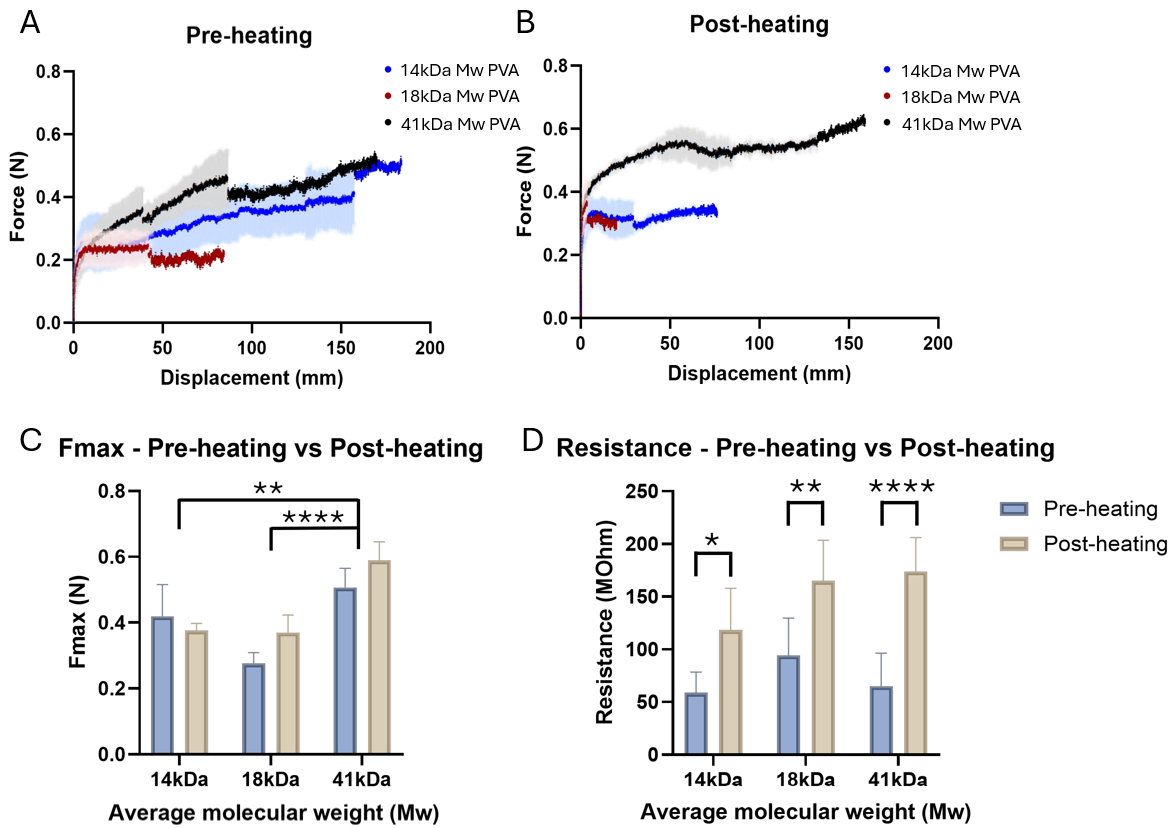
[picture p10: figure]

Fig. 7: Characterisation of pre- and post-heating fibre collectors made from different PVA types
A. Force-displacement curve of different PVA types pre-heating, B. Force-displacement curve of different PVA types post-heating, C. Fmax (N) of fibre collectors made from different PVA types pre- and post-heating, D. Electrical resistance (MOhm) of fibre collectors made from different PVA types pre- and post-heating.
Despite elevated electrical resistance, it was decided to incorporate a post-spinning heating step for future work, as this improved the fibre collectors’ stiffness, with an increase in Young’s modulus from 3.9MPa to 31.5MPa. This is favourable, as it prevents excessive deformation of the fibre collector resulting from tension during the electrospinning process. While 41kDa collectors exhibited the highest force resistance, 14kDa collectors showed the lowest level of electrical resistance, with a post-heating average of 120±40MOhm and a maximum of 150MOhm. Given that collectors with R>150MOhm were observed to impair electrospun fibre deposition, 14kDa collectors appear to be the most suitable for electrospinning. Additionally, processing of the 14kDa PVA, which is provided in the form of filaments, is more favourable compared to the 18kDa and 41kDa PVA which are supplied as crystals that easily escape dissolution and thus result in blockages during wet-spinning (Fig. 3). Based on these results, 14kDa PVA was selected for the subsequent steps of this work.

## 3.2 Production of electrospun hollow fibres

### 3.2.1 Suitability of the dissolvable fibre collector for electrospinning

After using a stainless-steel collector to identify the appropriate electrospinning parameters, such as tube-to-collector distance, solution extrusion speed, and voltage, the dissolvable fibre collector was tested for electrospinning of PCL/PDO eHFs. During this process, thinning of the dissolvable collector was observed due to tension generated by drawing it through the electrospinner. Additionally, it was found that after some time the PCL/PDO fibres only deposited onto one side of the collector, indicating insufficient rotation. Force transmission was tested by measuring the draw speed of a stainless-steel collector and a dissolvable fibre collector with an input speed of 0.5mm/s. While the stainless-steel wire showed speeds close to input (0.50±0.02mm/s), the dissolvable collector exhibited significantly impaired force transmission (0.21mm/s) and underwent mechanical failure. To address this, a tension controller and a tube for reduced friction during unwinding were installed (Fig. S4). When using this setup, the collector’s integrity was maintained without failure or visible deformation and the same speed for both collectors (0.50±0.02mm/s, 0.50±0.01mm/s) was recorded, indicating efficient force transmission.
The dissolvable fibre collector was then successfully applied for collecting PCL/PDO eHFs, as deposited material showed an even distribution, indicating functional rotation and sufficient electrical conductivity. Following electrospinning, measurements of the dissolvable collector diameter revealed that plastic deformation during electrospinning occurred within a reasonable range, with an average diameter reduction of 5.3±4.5% and a maximum of 10%. Finally, it was concluded that the produced dissolvable fibre collector presents a viable alternative to traditional stainless-steel collectors while enhancing scalability prospects.

### 3.2.2 Effects of draw speed on electrospun hollow fibre wall thickness

The speed at which a collector is drawn through the electrospinner dictates how much material is deposited. This in turn affects the wall thickness of the produced eHFs. To identify which draw speed correlates with the desired dimensions, speeds of 1mm/s, 1.5mm/s, and 2mm/s were tested. Given that a final post-stretch wall thickness of ~50µm is desired and assuming a ~50% reduction in wall thickness based on stretching, the eHFs were aimed to have a pre-stretch diameter of ~100µm.Based on the obtained light imaging data, a draw speed of 1mm/s correlated with a wall thickness of ~100µm (Fig. S5), with eHFs generated using the dissolvable fibre collector (PVA-based) exhibiting an average thickness of 105±22µm and eHFs generated using the stainless-steel collector (steel-based) showing an average thickness of 108±8µm. Based on the given results, a collector draw speed of 1mm/s was chosen for eHFs production.

### 3.2.3 Effects of stretching on electrospun hollow fibre dimensions

With the aim to establish longitudinally aligned microfibres for cell guidance, eHFs were stretched manually until resistance to plastic deformation was noted. The stretched PVA-based and steel-based eHFs showed an average length increase of 2.6±0.3x and 2.3±0.4x, respectively. Steel-based eHFs thus exhibited a lower increase in length, though no significant difference (p=0.3) was detected. To further analyse the effects of stretching, eHFs were imaged by SEM. Post-stretch eHFs showed a clear structural alignment compared to pre-stretch eHFs (Fig. S8).

Significant reductions in eHF diameter, wall thickness, and lumen diameter were noted, with an overall diameter of 198±12µm and 260±54µm, wall thickness of 41±11µm and 52±12µm, and lumen diameter of 89±13µm and 132±40µm observed for PVA- and steel-based eHFs, respectively (Fig. 8A). The post-stretch wall thickness, therefore, aligned well with the desired dimensions. It may also be noted that eHFs with an intact or removed collector core exhibited no significant differences, indicating that neither manual removal of the steel collector nor flushing of the dissolvable collector affect fibre quality.

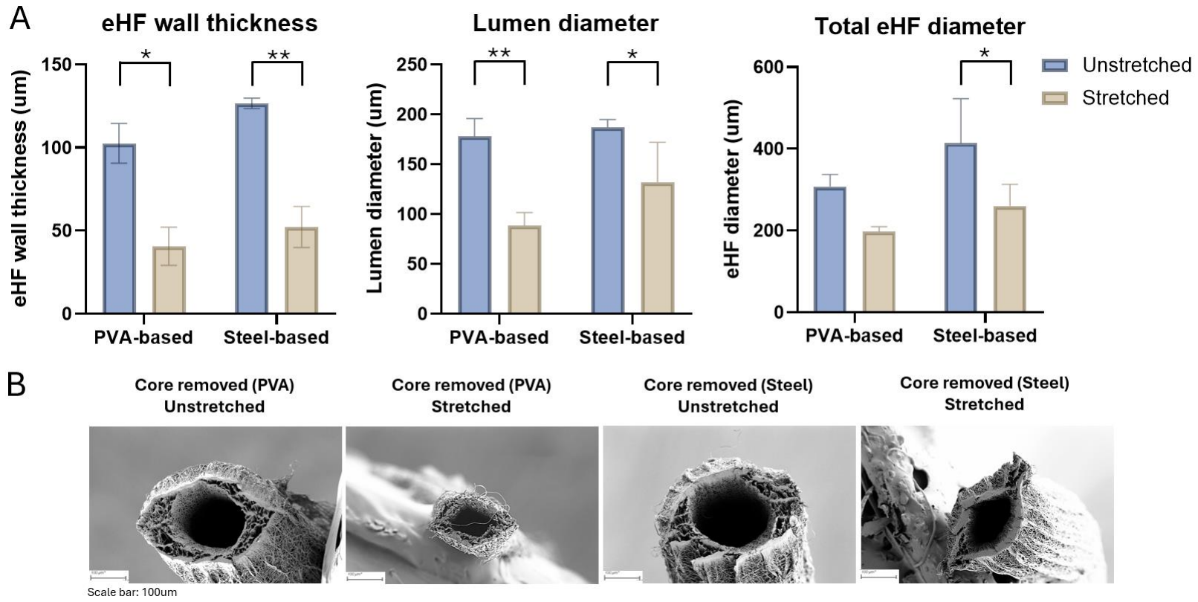
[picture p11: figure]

Fig. 8: Dimensions of pre- and post-stretch electrospun hollow fibres
A. Hollow fibre (HF) wall thickness, lumen diameter, and HF diameter of unstretched and stretched PVAand steel-based electrospun HFs, B. Cross-sectional scanning electron microscopy (SEM) images at a magnification of 160x, Scale bars: 100µm.

### 3.2.4 Effects of stretching on microfibre diameter and alignment

SEM images at high magnification were used to analyse the microfibres of which the eHFs are composed. A 30% and 23% reduction in microfibre diameter was observed following stretching, leading to diameters of 1.21±0.30µm for PVA-based and 1.03±0.22µm for steel-based eHFs, respectively (Fig. 9B). Given a desired post-stretch microfibre diameter of 0.5-1µm, this aligns with the targeted dimensions. The unstretched microfibre diameter of PVA-based eHFs was slightly larger (+0.4µm; p=0.04) than that of steel-based eHFs. This could potentially be explained by the higher electrical conductivity of stainless steel compared to PVA/PEDOT:PSS. A significant difference (p=0.006) was detected between the microfibre diameter of pre- and post-stretch PVA-based eHFs. Despite a clear reduction in microfibre diameter from 1.34±0.10µm pre-stretch to 1.03±0.22µm post-stretch, significance could not be determined for steel-based eHFs. No significant differences were observed between eHFs pre- and post-core removal. Alignment of eHFs presents an essential aspect, as it provides topographical guidance to aid the arrangement and differentiation of cells. Post-stretch microfibres showed a clear structural alignment (Fig. 9A), and directionality histograms displayed a significant difference (p<0.0001) pre- and post-stretch, as post-stretch microfibres exhibited increased alignment along the 0° axis (Fig. 9C). No significant differences were observed between pre- and post-core removal eHFs.

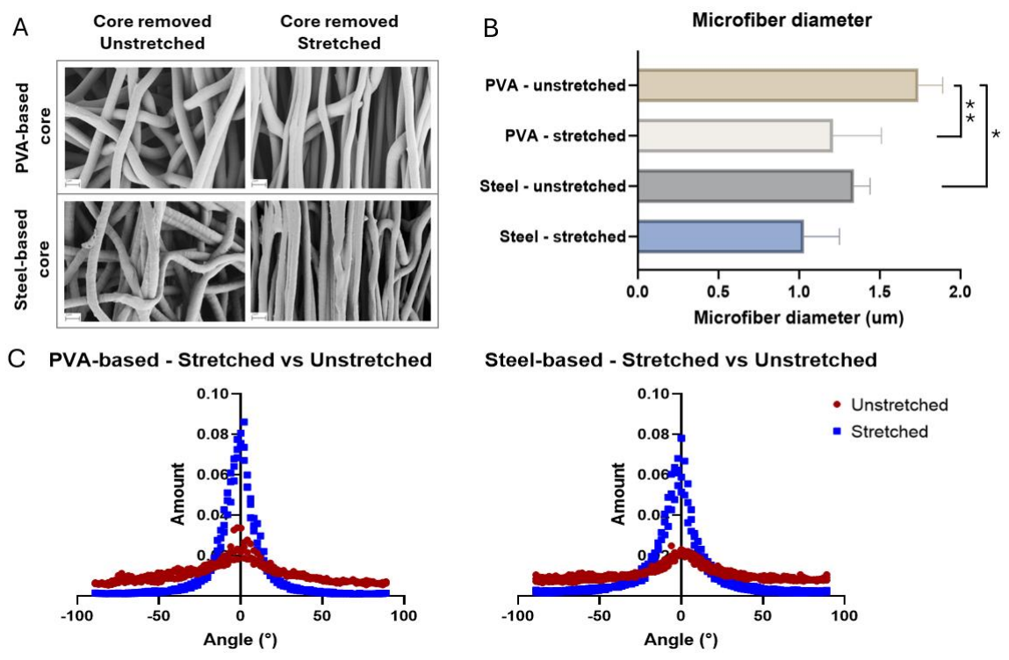
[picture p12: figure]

Fig. 9: Diameter and alignment of pre- and post-stretch electrospun microfibres
A. Scanning electron microscopy (SEM) images showing microfibres of electrospun hollow fibres (eHFs) at a magnification of 4.33k, Scale bars: 2µm, B. Microfibre diameter (µm) of unstretched and stretched PVA- and steel-based eHFs, C. Directionality histograms of unstretched and stretched PVA- and steel-based eHFs.

### 3.2.5 Removal of the dissolvable collector core

Following generation of the eHFs, the dissolvable collector needed to be removed from the eHF core by subjecting them to sonication. Fibre sections were placed in water and sonicated with five 5-minute runs at an amplitude of 40%. Following a total sonication time of 25 minutes, the collector had not dissolved (Fig. S10). To address this, fibre sections were pre-soaked in water at RT (min. 8h) prior to sonication; however, following five 5-minute sonication runs at 40% amplitude, significant quantities of collector residue were still visible. Next, eHFs were pre-soaked in 37°C (min. 8h) which resulted in clearly enhanced collector removal, indicating that elevated soaking temperatures facilitate the process. Nonetheless, some of the collector material remained. Applying two rounds of sonication following pre-soaking at RT plus pre-soaking at 37°C did not alleviate this. Full removal of the collector material by perfusion will be tested in the future.

## 3.3 Limitations

Several limitations related to methodology and materials need to be noted. Methodological limitations include the following. Experimenter’s experience influences wet-spinning and electrospinning outcomes. Wet-spinning, collector core removal and eHF stretching are manual processes which can introduce errors and variability. Viscosity measurements of the produced mixtures were not obtained. Materials limitations include the following. Only a limited molecular weight range for PVA was tested. The produced dissolvable collector exhibited moisture sensitivity, with excessive moisture loss leading to brittleness. A slight deterioration in the quality of eHFs was observed based on their morphological features, which could be linked to the use of

PDO that in its unprocessed form degrades over the course of a few months. Finally, complete removal of the dissolvable collector core of eHFs was not yet achieved.

# 4. Conclusions and Future Work

## 4.1 Conclusions

A protocol for the production of a reproducible dissolvable electrospinning collector was established. This collector was successfully employed to generate eHFs. The dissolvable fibre collector performed well compared to a traditional steel collector, and the removal process showed to have no significant effects on fibre quality. Electrospinning parameters required to achieve the desired fibre dimensions were identified. Furthermore, stretch-induced alignment of microfibres was confirmed. The obtained results set a good foundation for future work that will explore application of the generated eHF scaffold inside a bioreactor module to address current limitations in the field of skeletal muscle tissue engineering.

## 4.2 Future Work

### 4.2.1 Electrospun hollow fibre scaffold

The possibility of eliminating PDO from the current protocol will be explored, and removal of the dissolvable collector will be further investigated to ensure complete flushing of the collector material. Additionally, various analyses will be applied to further characterise the produced eHF scaffold. For example, micro-computed tomography (micro-CT) will be used to determine the scaffold’s pore size, porosity percentage, and potential spatial variations in porosity. Uniaxial tensile mechanical testing will be used to determine the mechanical properties of the eHFs. Biocompatibility of the scaffold will be tested based on a cytotoxicity assay. The structural and biological support the scaffold offers to cells will be analysed by assessing attachment, morphology, proliferation, and differentiation of cultured cells. Furthermore, differentiation of cells cultured on stretched versus unstretched eHFs will be assessed.

### 4.2.2 The bioreactor chamber and mechanical loading

The developed eHF scaffold is aimed to be incorporated into a soft flexible bioreactor chamber designed for the integration into dynamic mechanical platforms such as uniaxial stages or more complex multiaxial systems, e.g. the humanoid bioreactor platform developed by our group [24]. The chamber will be designed to host the eHF scaffold, support the influx and outflux of culture medium, and allow for efficient mechanical signal transduction. The final design is aimed to accommodate several hundred eHFs with direct perfusion via ports. A direct inlet and outlet to the chamber will additionally allow for medium changes with muscle-specific differentiation factors. The developed chamber will be assessed for its functionality and integrity, specifically during fluid flow and mechanical loading. Once functionality has been confirmed, eHFs with intact dissolvable collector cores will be plotted into the chamber followed by simultaneous core flushing. Subsequently, a uniaxial tension device will be tested for uniform stretching of all eHFs. Effective force transmission within the eHF bioreactor module will need to be ensured and stability of the scaffold under mechanical loading must be confirmed. Human myoblasts will then be seeded onto the scaffold inside the chamber followed by mechanical stimulation.

### 4.2.3 Functionality and utility of the muscle tissue construct

Typical morphological features of muscle tissue will be assessed, including sarcomeric banding patterns, multinucleation, and a hierarchical tubular architecture [25].Myotube alignment will be measured based on directionality assays, and the myoblast fusion index will be identified based on the number of detected nuclei per myotube. Notably, increased levels of alignment and a higher fusion index correlate with enhanced tissue maturity [26]. Functional features such as twitching and contractile force generation will also be evaluated. Using immunofluorescent staining and quantitative polymerase chain reaction (qPCR), the expression levels of skeletal muscle differentiation markers will be identified to determine the stages of tissue maturation. This will likely include myoblast determination protein 1(MyoD), myogenin, and myosin heavy chain (MHC), which are linked to proliferation, differentiation, and myotube maturation, respectively [27]. Other skeletal muscle differentiation markers that may be tested include alphaactinin and desmin [28].
Once synthesis of mature muscle has been confirmed, preliminary drug response assays will be performed to analyse responses to drugs with well-known effects, such as blebbistatin, a myosin II inhibitor known to suppresses muscle contraction [29], and chemotherapy drug cisplatin, a toxic agent known to induce a decrease in muscle mass and myofibre diameter causing skeletal muscle dysfunction [30]. (https://doi.org/10.1016/j.taap.2014.05.001)

### 4.2.4 Gantt Chart

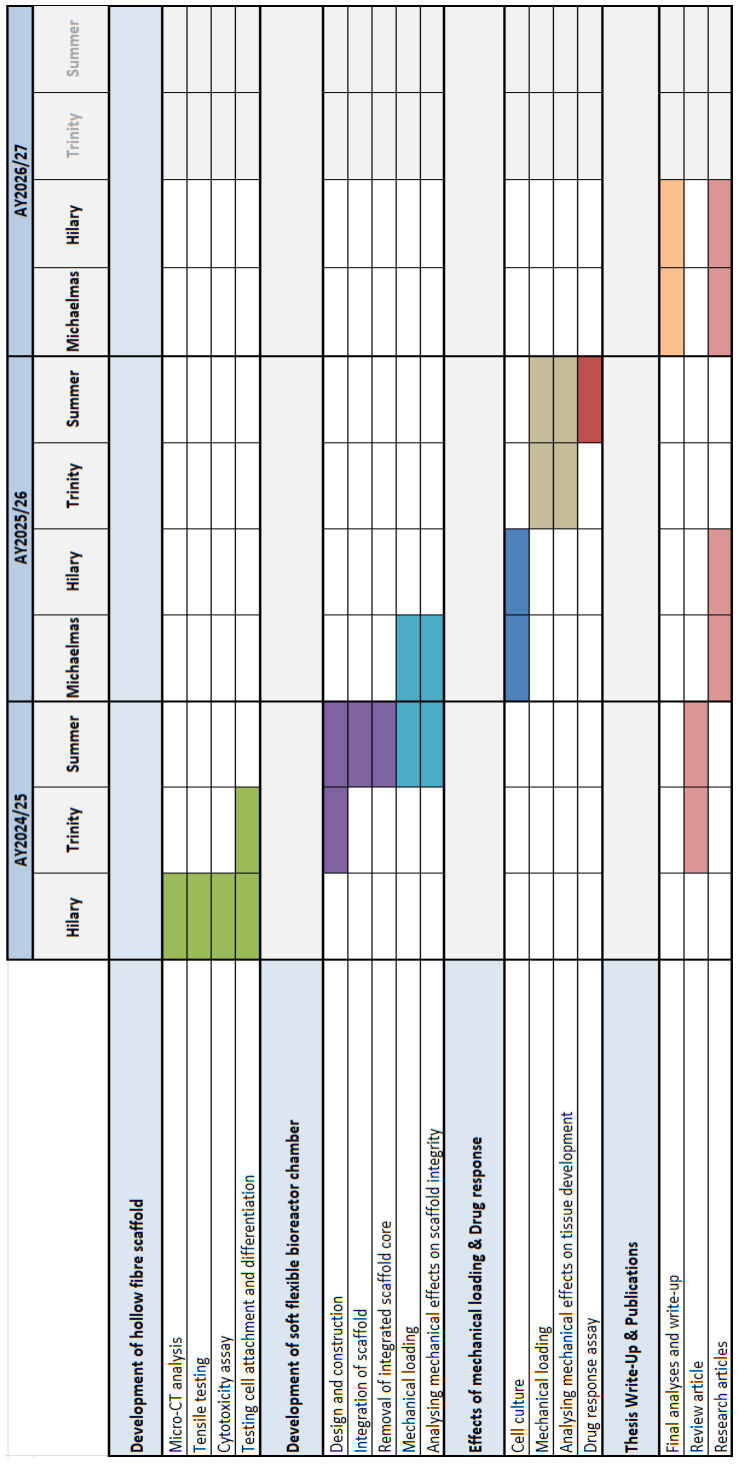
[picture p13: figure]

### 4.2.5 Risk mitigation plan

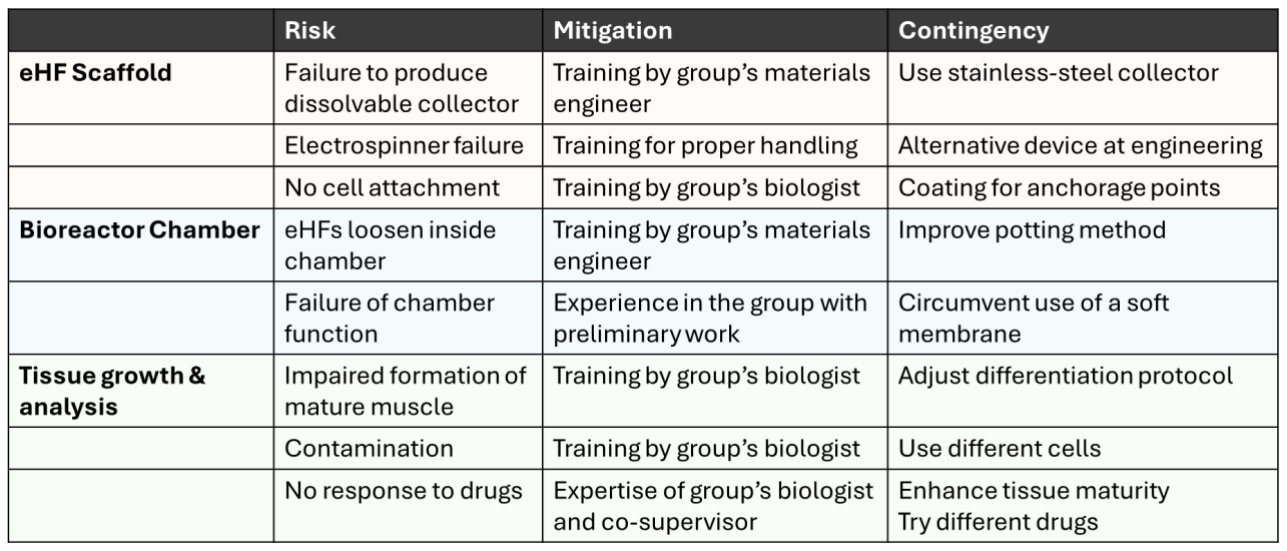
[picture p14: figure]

# 5. References

[1] C. McCuller, R. Jessu, and A. L. Callahan, ‘Physiology, Skeletal Muscle’, in StatPearls, Treasure Island (FL): StatPearls Publishing, 2024. Accessed: Dec. 02, 2024. [Online]. Available: http://www.ncbi.nlm.nih.gov/books/NBK537139/
[2] T. Zidarič, M. Milojević, J. Vajda, B. Vihar, and U. Maver, ‘Cultured Meat: Meat Industry Hand in Hand with Biomedical Production Methods’, Food Eng. Rev., vol. 12, no. 4, pp. 498–519, Dec. 2020, doi: 10.1007/s12393-020-09253-w.
[3] ‘Skeletal Muscle | Anatomy and Physiology I’. Accessed: Dec. 09, 2024. [Online].
Available: https://courses.lumenlearning.com/suny-ap1/chapter/skeletal-muscle/
[4] A. Kaczmarek et al., ‘The Role of Satellite Cells in Skeletal Muscle Regeneration—The Effect of Exercise and Age’, Biology, vol. 10, no. 10, p. 1056, Oct. 2021, doi: 10.3390/biology10101056.
[5] ‘Musculoskeletal health’. Accessed: Dec. 02, 2024. [Online]. Available: https://www.who.int/news-room/fact-sheets/detail/musculoskeletal-conditions
[6] E. M. McNally and P. Pytel, ‘Muscle Diseases: The Muscular Dystrophies’, Annu. Rev. Pathol. Mech. Dis., vol. 2, no. Volume 2, 2007, pp. 87–109, Feb. 2007, doi: 10.1146/annurev.pathol.2.010506.091936.
[7] R. R. Wolfe, ‘The underappreciated role of muscle in health and disease2’, Am. J. Clin. Nutr., vol. 84, no. 3, pp. 475–482, Dec. 2006, doi: 10.1093/ajcn/84.3.475.
[8] ‘ALURES statistics - Section 2 : Uses of animals for research, testing, routine production and education and training purposes - European Commission’, Environment Alures statistics. Accessed: Dec. 02, 2024. [Online]. Available: https://webgate.ec.europa.eu/envdataportal/content/alures/section2_number-of-uses.html
[9] V. T. von Kortzfleisch et al., ‘Do multiple experimenters improve the reproducibility of animal studies?’, PLOS Biol., vol. 20, no. 5, p. e3001564, May 2022, doi: 10.1371/journal.pbio.3001564.
[10] C. B. Brink and D. I. Lewis, ‘The 12 Rs Framework as a Comprehensive, Unifying Construct for Principles Guiding Animal Research Ethics’, Animals, vol. 13, no. 7, Art. no. 7, Jan. 2023, doi: 10.3390/ani13071128.
[11] G. A. Van Norman, ‘Limitations of Animal Studies for Predicting Toxicity in Clinical Trials: Is it Time to Rethink Our Current Approach?’, JACC Basic Transl. Sci., vol. 4, no. 7, pp. 845–854, Nov. 2019, doi: 10.1016/j.jacbts.2019.10.008.
[12] T. Rademakers, J. M. Horvath, C. A. van Blitterswijk, and V. L. S. LaPointe, ‘Oxygen and nutrient delivery in tissue engineering: Approaches to graft vascularization’, J. Tissue Eng. Regen. Med., vol. 13, no. 10, pp. 1815–1829, 2019, doi: 10.1002/term.2932.
[13] C. A. Powell, B. L. Smiley, J. Mills, and H. H. Vandenburgh, ‘Mechanical stimulation improves tissue-engineered human skeletal muscle’, Am. J. Physiol.-Cell Physiol., vol. 283, no. 5, pp. C1557–C1565, Nov. 2002, doi: 10.1152/ajpcell.00595.2001.

[14] Y. Wang et al., ‘Multiple Effects of Mechanical Stretch on Myogenic Progenitor Cells’, Stem Cells Dev., Mar. 2020, doi: 10.1089/scd.2019.0286.
[15] H. Eghbali, M. M. Nava, D. Mohebbi-Kalhori, and M. T. Raimondi, ‘Hollow Fiber Bioreactor Technology for Tissue Engineering Applications’, Int. J. Artif. Organs, vol. 39, no. 1, pp. 1–15, Jan. 2016, doi: 10.5301/ijao.5000466.
[16] J. Nicolas, S. Magli, L. Rabbachin, S. Sampaolesi, F. Nicotra, and L. Russo, ‘3D Extracellular Matrix Mimics: Fundamental Concepts and Role of Materials Chemistry to Influence Stem Cell Fate’, Biomacromolecules, vol. 21, no. 6, pp. 1968–1994, Jun. 2020, doi: 10.1021/acs.biomac.0c00045.
[17] S. Ferraris et al., ‘Topographical and Biomechanical Guidance of Electrospun Fibers for Biomedical Applications’, Polymers, vol. 12, no. 12, Art. no. 12, Dec. 2020, doi: 10.3390/polym12122896.
[18] R. J. Martin, ‘Development of vascular inspired electrospun hollow fibre membranes for use in 3D tissue culture’, http://purl.org/dc/dcmitype/Text, University of Oxford, 2022. Accessed: Dec. 09, 2024. [Online]. Available: https://ora.ox.ac.uk/objects/uuid:96e65892-b8d3-41c3-a50c-29819e43eb84
[19] S. M. Siadat, A. A. Silverman, C. A. DiMarzio, and J. W. Ruberti, ‘Measuring Collagen Fibril Diameter with Differential Interference Contrast Microscopy’, J. Struct. Biol., vol. 213, no. 1, p. 107697, Mar. 2021, doi: 10.1016/j.jsb.2021.107697.
[20] S. Y. Chew, R. Mi, A. Hoke, and K. W. Leong, ‘The effect of the alignment of electrospun fibrous scaffolds on Schwann cell maturation’, Biomaterials, vol. 29, no. 6, pp. 653–661, Feb. 2008, doi: 10.1016/j.biomaterials.2007.10.025.
[21] M. Félétou, ‘Introduction’, in The Endothelium: Part 1: Multiple Functions of the Endothelial Cells—Focus on Endothelium-Derived Vasoactive Mediators, Morgan & Claypool Life Sciences, 2011. Accessed: Dec. 09, 2024. [Online]. Available: https://www.ncbi.nlm.nih.gov/books/NBK57145/
[22] H. Gao, J. Xiao, Y. Wei, H. Wang, H. Wan, and S. Liu, ‘Regulation of Myogenic Differentiation by Topologically Microgrooved Surfaces for Skeletal Muscle Tissue Engineering’, ACS Omega, vol. 6, no. 32, pp. 20931–20940, Aug. 2021, doi: 10.1021/acsomega.1c02347.
[23] X. Du, L. Yang, and N. Liu, ‘Recent Progress on Poly(3,4-Ethylenedioxythiophene):Poly(Styrenesulfonate) Bioelectrodes’, Small Sci., vol. 3, no. 7, p. 2300008, 2023, doi: 10.1002/smsc.202300008.
[24] P.-A. Mouthuy et al., ‘Humanoid robots to mechanically stress human cells grown in soft bioreactors’, Commun. Eng., vol. 1, p. 2, May 2022, doi: 10.1038/s44172-022-00004-9.
[25] F. M. Trovato, R. Imbesi, N. Conway, and P. Castrogiovanni, ‘Morphological and Functional Aspects of Human Skeletal Muscle’, J. Funct. Morphol. Kinesiol., vol. 1, no. 3, Art. no. 3, Sep. 2016, doi: 10.3390/jfmk1030289.
[26] A. Weisrock, R. Wüst, M. Olenic, P. Lecomte-Grosbras, and L. Thorrez, ‘MyoFInDer: An AI-Based Tool for Myotube Fusion Index Determination’, Tissue Eng. Part A, vol. 30, no. 19–20, pp. 652–661, Oct. 2024, doi: 10.1089/ten.tea.2024.0049.

[27] Y. Yoshimoto, M. Ikemoto-Uezumi, K. Hitachi, S. Fukada, and A. Uezumi, ‘Methods for Accurate Assessment of Myofiber Maturity During Skeletal Muscle Regeneration’, Front. Cell Dev. Biol., vol. 8, Apr. 2020, doi: 10.3389/fcell.2020.00267.
[28] J. A. Kim, Y. H. Shon, J. O. Lim, J. J. Yoo, H.-I. Shin, and E. K. Park, ‘MYOD mediates skeletal myogenic differentiation of human amniotic fluid stem cells and regeneration of muscle injury’, Stem Cell Res. Ther., vol. 4, no. 6, p. 147, Dec. 2013, doi: 10.1186/scrt358.
[29] M. Watanabe et al., ‘Blebbistatin, a myosin II inhibitor, suppresses contraction and disrupts contractile filaments organization of skinned taenia cecum from guinea pig’, Am. J. Physiol.-Cell Physiol., vol. 298, no. 5, pp. C1118–C1126, May 2010, doi: 10.1152/ajpcell.00269.2009.
[30] H. Sakai et al., ‘Mechanisms of cisplatin-induced muscle atrophy’, Toxicol. Appl. Pharmacol., vol. 278, no. 2, pp. 190–199, Jul. 2014, doi: 10.1016/j.taap.2014.05.001.

# 6. Appendix

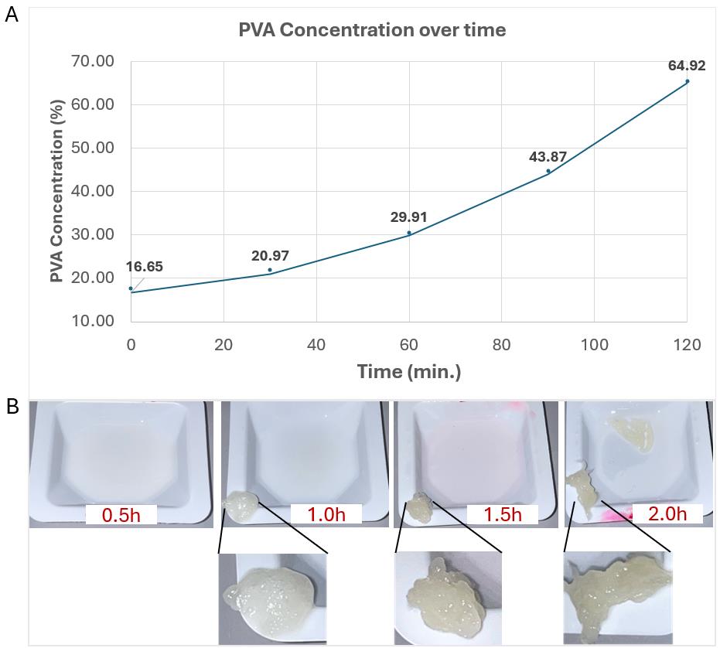
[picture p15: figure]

Fig. S1: Curing test
A. PVA concentration (%) over heating time (min.), B. Curing tests performed following 0.5h, 1.0h, 1.5h, and 2.0h heating showing zoom-in images of (semi-)cured samples.

Following heating, the solution properties changed, with an initial smooth texture and subsequent drying and accumulation of air bubbles (Fig. S2A,B,C). Within 10 minutes following production, the mixture began to harden. By 40 minutes, extrusion became difficult due to encapsulated air. After one hour, extrusion was no longer possible. These observations suggested that a ~15-minute window post-heating should be used for optimal wet-spinning to avoid significant texture changes.

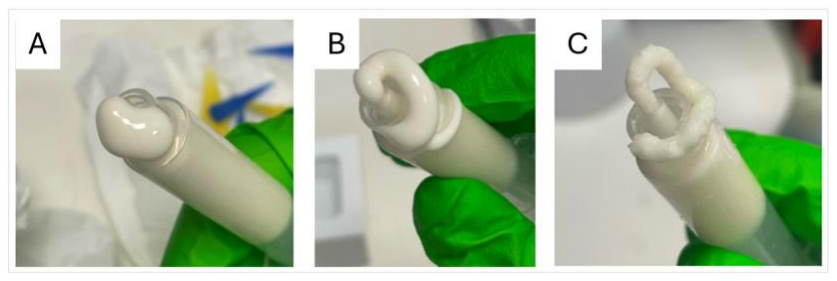
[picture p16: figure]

Fig. S2: Post-heating PVA solution
A. Immediately after heating showing smooth texture, B. 10 min. following heating showing change in texture, C. 40 min. following production showing drying of solution and accumulation of air bubbles.

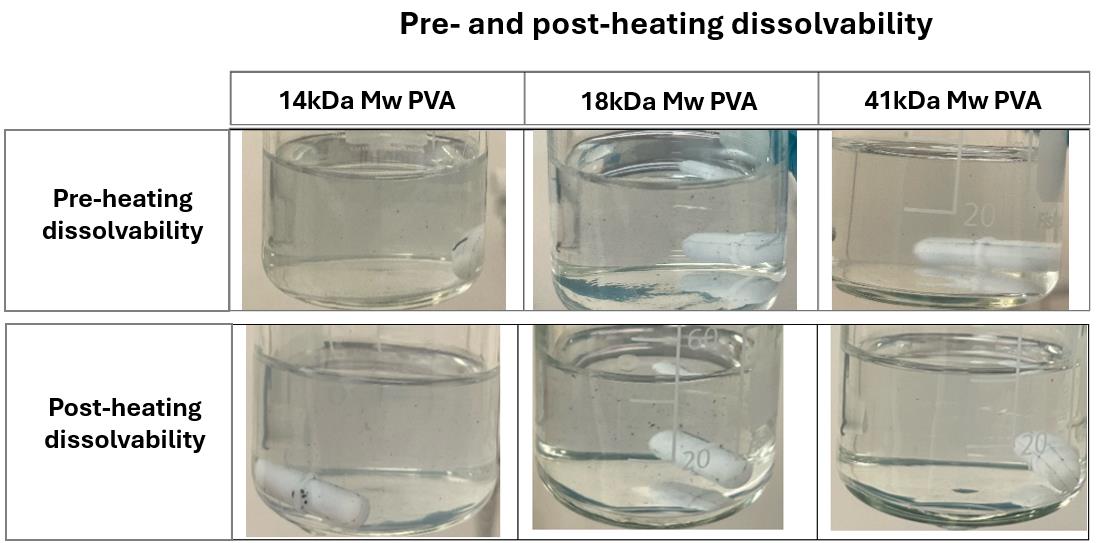
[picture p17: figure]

Fig. S3: Dissolvability test Pre- and post-heating dissolvability of the fibre collector made from different PVA types. Pictures show collector dissolution following 6 min. in water under constant stirring.

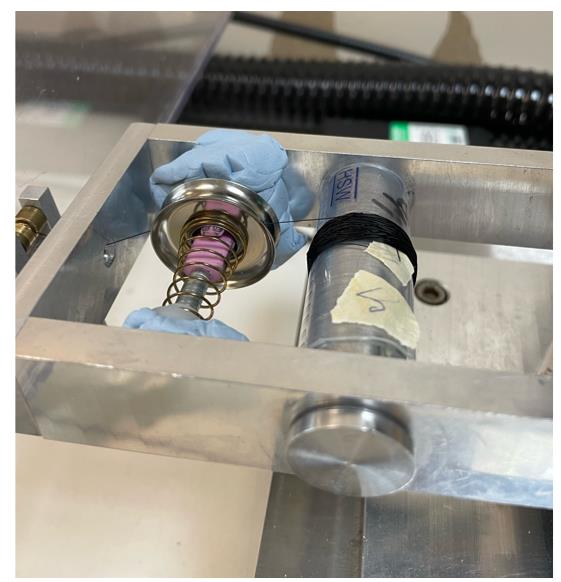
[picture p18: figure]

Fig. S4: Instalments for minimised tension of the dissolvable fibre collector A tension controller (left) and a plastic tube (right) on the rotating spool of the electrospinner for reduced friction.

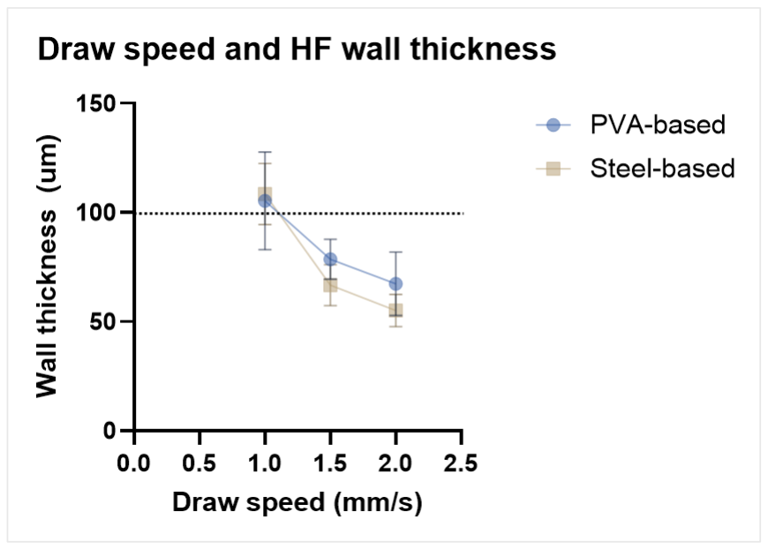
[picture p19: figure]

Fig. S5: Draw speed and hollow fibre wall thickness Electrospinning draw speed and wall thickness of PVA- and steel-based electrospun hollow fibres (eHFs).

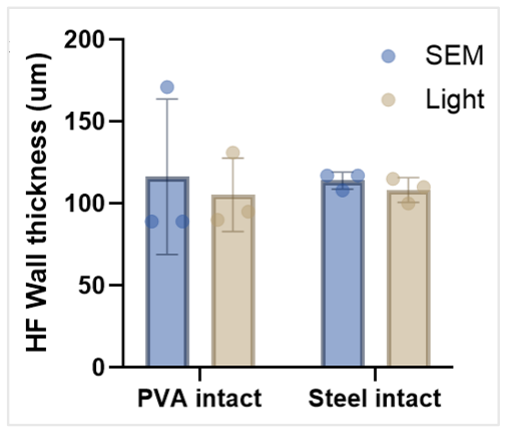
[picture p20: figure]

Fig. S6: SEM vs light microscopy data for hollow fibre wall thickness Comparison of scanning electron microscopy (SEM) and light microscopy data of the wall thickness of PVA- and steel-based electrospun hollow fibres (eHFs).

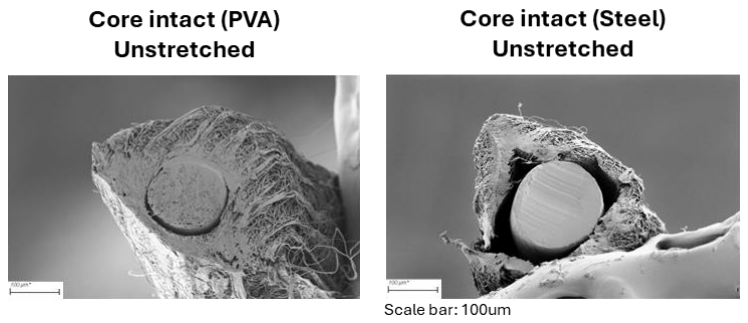
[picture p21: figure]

Fig. S7: Hollow fibre cross sections Cross sections of unstretched electrospun hollow fibres (eHFs) with intact PVA and steel core, Scale bars: 100µm.

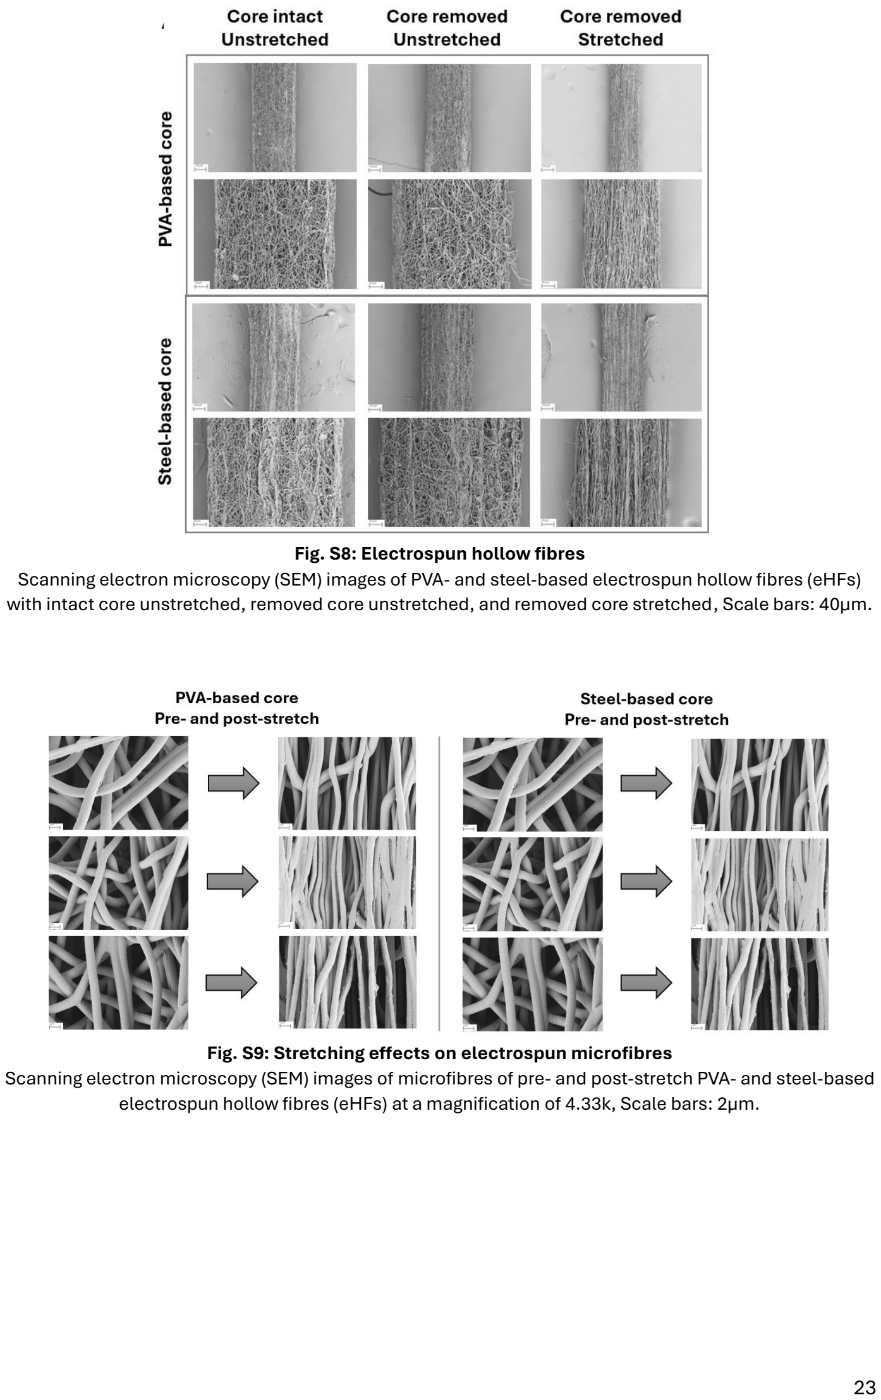
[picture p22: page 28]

Fig. S8: Electrospun hollow fibres Scanning electron microscopy (SEM) images of PVA- and steel-based electrospun hollow fibres (eHFs) with intact core unstretched, removed core unstretched, and removed core stretched, Scale bars: 40µm.

Fig. S9: Stretching effects on electrospun microfibres Scanning electron microscopy (SEM) images of microfibres of pre- and post-stretch PVA- and steel-based electrospun hollow fibres (eHFs) at a magnification of 4.33k, Scale bars: 2µm.

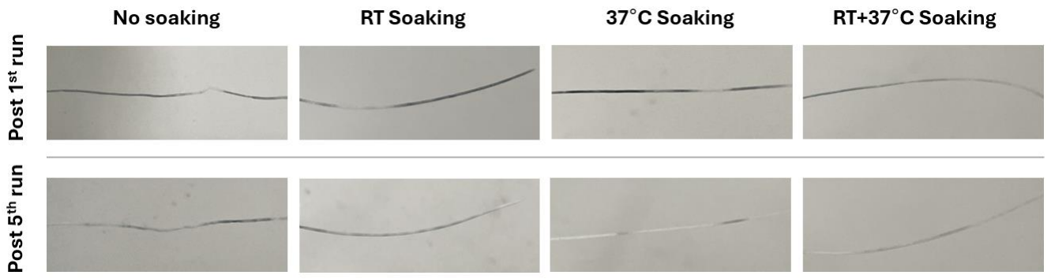
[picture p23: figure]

Fig. S10: Removal of collector core PVA-based electrospun hollow fibres (eHFs) following one and five 5-min. sonication runs at 40%amp with no pre-soaking, pre-soaking at room temperature (RT), pre-soaking at 37ºC, and two sets of pre-soaking (RT, 37ºC) and sonication. eHF material in white. Dissolvable collector material in black.

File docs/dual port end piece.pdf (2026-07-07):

## One end piece — two inlets (ICS axial + ECS 90°)

The opposite end is identical but mirrored, carrying the two outlets.

ICS in

Axial port — medium
THROUGH the fibres (lumens)

lumen header

Potting plug —
the wall between the two circuits
shell space (ECS) — around the fibres | Flexible middle slips over the inboard spigot (threaded-ring joint)

ECS in (90°)

Radial port — medium BETWEEN the fibres (into the shell). Same silicone-over-spigot + O-ring.

fibres potted at the plug, running into the flexible middle

Rule: ICS port sits OUTBOARD of the potting (feeds the lumens); ECS port sits INBOARD of the potting (feeds the shell). If the 90° branch opened outboard of the plug, the two circuits would short together.

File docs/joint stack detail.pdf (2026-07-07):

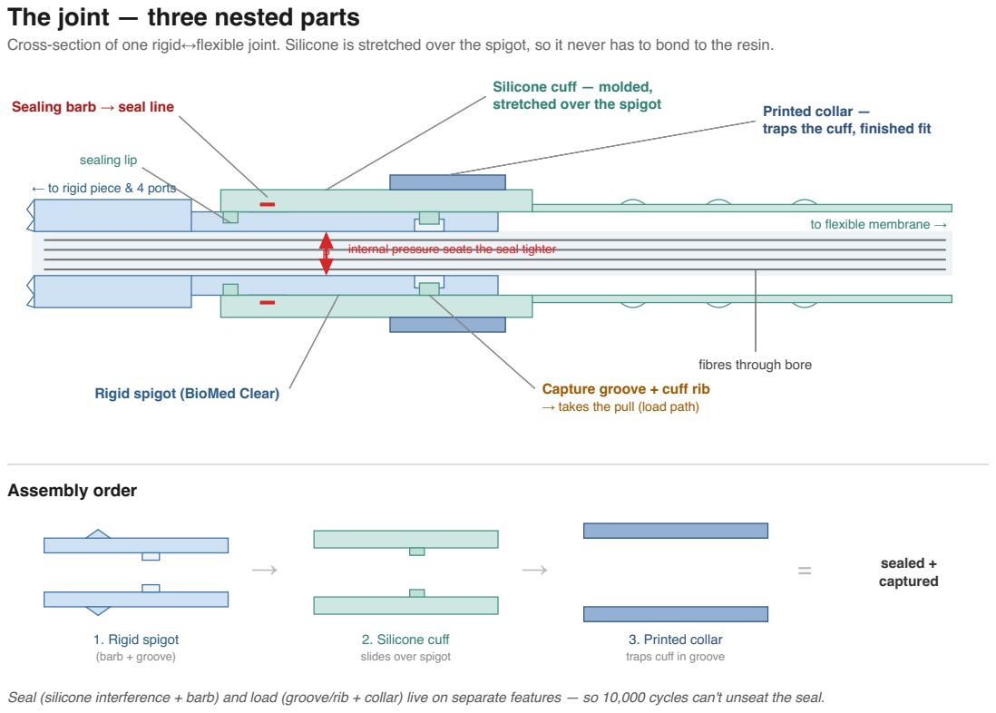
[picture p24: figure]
The joint — three nested parts; Sealing barb → seal line; Silicone cuff — molded,; stretched over the spigot; Printed collar —; traps the cuff, finished fit; sealing lip; Rigid spigot (BioMed Clear); Capture groove + cuff rib; → takes the pull (load path); fibres through bore; ← to rigid piece & 4 ports; to flexible membrane →; Assembly order; 1. Rigid spigot; (barb + groove); 2. Silicone cuff; slides over spigot; 3. Printed collar; traps cuff in groove; sealed +; captured

Cross-section of one rigid↔flexible joint. Silicone is stretched over the spigot, so it never has to bond to the resin.

internal pressure seats the seal tighter

Seal (silicone interference + barb) and load (groove/rib + collar) live on separate features — so 10,000 cycles can't unseat the seal.

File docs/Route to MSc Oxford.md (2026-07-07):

# Route to MSc @ Oxford — Living Strategy Document

> **Single source of truth** for the goal: securing an **Oxford research degree** (MSc by Research, upgradeable to DPhil) with a **core in ML-based control for compliant / embodied robotic systems**, the **tendon-driven humanoid bioreactor as the flagship testbed**, and a parallel **startup track** (the safety layer for "physical AI").
>
> This is a *living* document. Add ideas, meeting notes, and decisions as they arise during the Oxford internship. It builds toward a **bulletproof plan for how and when to approach supervisors** with a research proposal, and **which department / funding / founding route** to take.
>
> ⚠️ It does **not** yet contain a dedicated research proposal — that is built separately over time (§7 scaffold), fed by the lab needs-finding in §6 and the thesis-seed directions in §7.

**Last updated:** 2026-06-30 · **Owner:** Marcel · **Status:** Active — internship phase

### How to use / update this doc
- Treat §2 (North Star), §3 (Principles) and §4 (Why me) as **stable**; revise rarely.
- Drop new ideas into §5 (directions), §6 (needs-finding), §12 (open questions), or §13 (action items).
- Run any "completely different" idea through the **two-question filter** in §8b before acting on it.
- Log every meaningful change in §16 (Changelog) with a date.
- Placeholders for your input are marked `>> [ ... ]`.

---

## 1. Snapshot (update freely)

- **Where I am now:** Research internship at NDORMS / Mouthuy lab, Oxford — building the soft hollow-fibre bioreactor chamber (Marie Kruth's DPhil). Mouthuy has transferred to **Materials**; his lab is increasingly working with humanlike / tendon-driven robotics.
- **Research core (recentred):** **safe/stable learning-based control for compliant / embodied robotic systems** — my passion *and* sharpest edge, and Furieri's exact methods. The **humanoid bioreactor is the flagship testbed** (Mouthuy co — advantage, internship value, novel compliant-control platform all retained), **not the point**.
- **Furieri fit — methods confirmed on paper.** His theme *"Learning-Based Control with Closed-Loop Guarantees"* (NN controllers for nonlinear systems; RL policy parametrizations; guarantees *by construction*) maps almost word-for-word onto the tendon-driven problem, with a specific **port-Hamiltonian / energy-based bridge** (§10f).
- **Supervisor model:** **Furieri (ES primary) + Mouthuy (co)**; degree = **apply to the funded DPhil in Engineering Science**, decide MSc-vs-DPhil at transfer. **PhD-vs-MSc is resolved** — the self-funded MSc(R) as a *destination* is dominated (§9f).
- **Startup (crystallised):** the **safety / stability layer for learned control of compliant ("physical AI") robots** — a hardware-agnostic control-software layer, portable off the bioreactor (§11). **Founding path: root in the UK (Oxford spinout + strong PhD-founder visas), expand into the US.**
- **Two things NOT yet settled (research):** (1) confirm Furieri wants to aim these methods at a **robot** (his testbeds are infrastructure); (2) **name the novel thesis contribution** — methods-fit ≠ thesis (§7).
- **Key hurdle:** funding (international fees + average grades) — target supervisor-grant + German funding, not merit scholarships (§9c).
- **Hard deadline:** **December 2026 / January 2027** scholarship round for **2027-28 entry**.
- `>> [ current top-of-mind note: ... ]`

---

## 2. North Star

Get admitted to an **Oxford research degree** on a project whose core is **ML-based control for compliant / embodied robotic systems**, that:
1. Sits genuinely at **robotics + embodied AI + learning-based control with guarantees**.
2. Uses the **tendon-driven humanoid bioreactor as its flagship testbed** (retaining my unfair advantage).
3. **Maximises admission odds** via my advantages + warm supervisors (Furieri + Mouthuy).
4. **Keeps the DPhil option open** — apply to the DPhil, decide MSc-vs-DPhil at transfer (§9).
5. **Keeps a startup path open** on the control-software layer — **UK-rooted, US-expansion** (§11).

Robotics/control anchor + credential home: **Prof. Furieri** (Engineering Science). Platform/domain anchor: **Prof. Mouthuy** (Materials). Department leaning **ES**, formally decided at application.

Secondary / backstop: US/EU PhD programmes (MIT Raman Lab, UIUC, Northwestern, EPFL, TU Delft) as later-stage alternatives.

---

## 3. Guiding principles (hard-won, keep visible)

- **The core is the control; the biology is the application.** My passion *and* edge is ML control for compliant/embodied systems. The humanoid is the **flagship testbed, not the point** (more convergent on my edge, not less).
- **The Devanthro connection is my single strongest differentiator** — attached to the **project and the people**, not the department; it survives an ES registration intact (§10a).
- **Safe-by-construction, not post-hoc.** On a compliant robot driving a tissue chamber, a learned controller cannot occasionally wander unstable — it would damage the tendons or the culture. Guarantees-*by-construction* are **operationally necessary** here — and, not coincidentally, the **core of the startup** (§11a).
- **Methods-fit ≠ thesis.** Finding the paragraph on Furieri's site that matches my system is easy; the **novel contribution is what I *add*** (§7).
- **Converge, don't diffuse.** Depth that compounds beats breadth that diffuses. Pick and go deep on the robotics-control core.
- **The friendship strengthens the bet — it does not replace it.** Furieri's methods map *onto* my platform's control problem; knowing him argues for going *deeper* on the robot.
- **Protect the Furieri friendship — don't instrumentalise it.** Let it be real; read his work; let the supervision conversation *emerge* via a peer-level technical exchange (§10f).
- **Startup = founder–market fit, not topic heat.** The startup rides the **control-software layer** (my edge), not bio (slow/regulated/capital-heavy) and not Furieri's energy/industrial domains (not my edge).
- **Stay Pierre-anchored via the testbed** — keeps Mouthuy as co, the admission advantage, and the internship's compounding value.
- **Let the platform's shared pain define the application problem** (§6). My unique value is *translation*.
- **The internship is maximised when it *compounds into* the degree** — show Pierre my robotics/control thinking, not just bench diligence.
- **The credential label is second-order; the work is first-order.** Thesis + publications + the system I built define me. (And publications double as **immigration + fundraising assets** — §11c.)
- **27 is not late — and a funded PhD is not "lost time."** The average high-growth-startup founder is ~45, and success rates rise with age well into the 40s; finishing a deep-tech PhD at ~31 with a technical moat, network, IP, and O-1/DeepMind credibility is *young*, not behind. The PhD **builds the company's foundation while I'm paid**, and can *incubate* the startup rather than merely precede it (§9f).
- **Optionality:** prefer moves that keep multiple futures open (academic + entrepreneurial; MSc + DPhil; UK + US).

---

## 4. Why me — unfair advantages (candidacy spine)

- **I helped build the exact robot.** At **Devanthro**, I worked on the humanoid (tendon-driven, series-elastic) platform.
- **My BSc thesis is the empirical seed of the PhD.** An **RL/ANN-based control algorithm for this exact tendon-elastic hardware**, tackling nonlinear control under tendon elasticity. The arc: **BSc = make it work empirically; PhD = make it *provably* work** (stable by construction — §10f).
- **The lab's humanoid bioreactor *is* a modified Devanthro shoulder joint.** Mouthuy et al. (2022, *Communications Engineering*) has **Rafael Hostettler / Devanthro as a co-author** → industrial continuity.
- **My current internship work is the physical interface** between the eHF muscle tissue and that robot.
- **This advantage survives an ES registration** (§10a) and is what makes me competitive for an ES place despite average grades — I arrive with a de-risked, ready-to-run, methodologically-matched **testbed**.

---

## 5. Candidate research directions (core recentred; selection driven by §6 + §7)

**Research core = safe/stable learning control for compliant/embodied robotic systems.** The humanoid bioreactor is the flagship testbed; direction **A** is the lead. Any *new* "completely different" idea must pass the §8b two-question filter.

| ID | Direction (short) | One-line description |
|----|---|---|
| **A** *(lead)* | Closed-loop, guaranteed-stable RL control of the humanoid bioreactor | NN/RL controller for the tendon-elastic system with **closed-loop guarantees by construction**; precise programmable strain + tissue-responsive feedback. The methods core; the bioreactor is the testbed. |
| **B** | Robotic automation of fibre potting & chamber assembly | Deformable-object handling + vision QC; direct extension of the internship. |
| **C** | Vision-based contractile readout + autonomous drug/geroprotector screening loop | Longevity bridge: muscle as a sarcopenia model. |
| **D** | Smart point-of-care cell-therapy manufacturing bioreactor | Closed-system, AI process control + vision QC. |
| **E** | Biohybrid actuators / muscle-powered robots | "Robotics + tissue engineering," most literal sense. |

- **Defensibility:** **A › B › C › D › E**
- **Startup potential (of the *application*):** **D › C › A › B › E** — but the startup thesis rides the **domain-general control-software layer**, not any single bio application (§8a, §11).
- **Bottom line:** lead with **A** as the flagship testbed for the control core. **B is the fallback** if the lab's shared pain is assembly/reproducibility. §6 sharpens the application; §7 names the novel contribution.

`>> [ new direction ideas — run through §8b filter first: ... ]`

---

## 6. Lab needs-finding (sharpens the application problem)

**Goal:** interview everyone, understand each project's interaction with the robot, and surface the **highest-value problem in the shared control / stimulation / feedback layer** — my lane. A well-defined, control-flavoured shared problem is the **natural bridge project to bring to both Furieri and Mouthuy**, and the lab are my **first "users"** → shared pain = early market validation for the control-software layer (§11).

### Interview template (ask everyone the same core set)
1. **What mechanical regime does your tissue need, and why that one?** *(principled vs guessed)*
2. **Walk me through running a stimulation session today, start to finish.** *(workflow friction)*
3. **Where does the platform limit you — what do you babysit, redo, or work around?** *(pain / automation openings)*
4. **How do you know the stimulation did what you intended — what do you measure, and when?** *(the feedback gap)*
5. **If the robot could do one thing it can't today, what would it be?** *(latent demand)*

> Q1 & Q4 most likely surface the control-shaped problem: fixed/guessed regimes with no tissue feedback = the open-loop gap my (guaranteed) closed-loop control closes.

### Guardrails
- **Stated wishes ≠ real needs** — capture the raw complaint *and* my translation into a control problem.
- **Don't pre-decide** — log pains pointing *away* from embodied control (→ direction B).
- **Stay in the shared control/feedback layer**, not anyone's specific biology.
- **Loop Pierre in early** — reads as platform-mapping, not stealth.

### Synthesis table (running — add a row per conversation)

| Person | Project / tissue | How they use the platform | Pains & workarounds | Stated wishes | My translation → candidate problem | Generalises to other labs? |
|---|---|---|---|---|---|---|
| `>> [ ]` | | | | | | |
| `>> [ ]` | | | | | | |

### Emerging patterns
- `>> [ shared problem #1: ... ]`
- **Working hypothesis of the highest-value problem:** `>> [ ... ]`

---

## 7. Research proposal — TO BE BUILT (scaffold + thesis-seed directions)

*No proposal drafted yet. The application problem comes from §6; the **novel contribution** is named below (methods-fit ≠ thesis).*

**Thesis-seed directions (the "what's genuinely new"):**
- **Extend guaranteed-stable learning-control to the specific structure of tendon-elastic actuation** — the nonlinearities and *coupling* of a multi-tendon, series-elastic system. Elastic energy storage makes **energy-based / passivity / port-Hamiltonian** formulations a natural fit (aligns with Furieri's port-Hamiltonian work — §10f).
- **Guarantees under a *changing* plant.** As tissue develops and mechanically feeds back, the plant changes; making closed-loop guarantees hold under this drift is novel, hard, and platform-motivated.
- `>> [ refine / add candidate contributions: ... ]`

**Checklist a strong proposal must satisfy:**
- [ ] **Original research question** — a novel *contribution* (above), not just "his controller class fits my system."
- [ ] Clear **unsolved problem** (open-loop, imprecise, feedback-free stimulation on compliant hardware; no safe-by-construction learned controller).
- [ ] **Robotics/control novelty pitched to Furieri** — safe/stable learning control of a nonlinear compliant system; my platform as a novel testbed; the port-Hamiltonian angle.
- [ ] **Why me** (§4), framed around the science.
- [ ] **Feasible scope** + milestones (§9).
- [ ] A **demonstrable result** ≥ MSc-R bar with a path to the DPhil bar.
- [ ] **Supervisors + fit** (Furieri primary + Mouthuy co).
- [ ] Honest **risk/contingency** note.

`>> [ proposal drafts / fragments here when ready ]`

---

## 8. Strategic framing notes (reference)

### 8a. Discovery instrument vs product / where the startup lives
The **humanoid = the "wind tunnel"** where control intelligence is discovered/validated; it never scales as a product. The **commercial asset = the learned, guaranteed-stable control-software / policy layer** — hardware-agnostic and portable across compliant/contact-rich robots. The DPhil generates the IP + credibility; the startup commercialises the software layer (full thesis in **§11**).

### 8b. The two-question filter (run any "completely different" idea through this)
- (a) Does it excite me **more**, *sustainably* — not just today?
- (b) Do I have a **defensible edge**, or am I starting from zero?
- **Both yes → stress-test it.** Either no → shiny-object syndrome in a lab coat.

### 8c. Startup reframe
Startup success tracks **unfair founder–market fit**, not topic trendiness. The startup rides my edge (robotic control software), not bio (slow/regulated/capital-heavy) and not Furieri's energy/industrial domains (not my edge).

### 8d. "Directly helps people" split (reference)
- **Therapeutic device** (bioartificial liver/kidney, hollow-fibre based — my expertise): most literal help but a 10–15-yr regulatory path, startup graveyard. Long-horizon ambition, not an MSc-to-startup play.
- **Smart manufacturing** (direction D): better fit than a device, still slower than a control-software play.
- Reference facts: manual CAR-T ~$400k/patient, labour ~40%, 2–5% contamination, automation → ~$100k; CGT manufacturing market ~$26.6B by 2035.

### 8e. Converge, don't diffuse — three concentric options (ranked)
1. **Robotics-control core, humanoid bioreactor as flagship testbed — Furieri (primary) + Mouthuy (co).** Passion + edge + advantage + clean ES credential. **Strongest.**
2. **Furieri-anchored control project, application broadened, no Mouthuy.** Keeps Luca + control skill; drops the platform advantage.
3. **A completely different topic (e.g., Furieri's grid/industrial domain), neither advantage nor passion.** No moat. **Weakest.**

### 8f. Recentring — three "optimise-for-X" disentangled
1. **My passion + edge → robotics / embodied control.**
2. **Furieri's hottest markets → grid / transport / industrial reliability.** Fundable, and where his entrepreneurial energy is — but a domain I have *no edge in* (the founder–market-fit trap).
3. **My admission advantage → the bio/Mouthuy platform.**
**Resolution:** center on **(1)**; keep the humanoid as the flagship **testbed** to retain **(3)**; point the startup at the control-software layer.

### 8g. The startup rarely falls straight out of the PhD topic
It comes from skills, network, an entrepreneurial supervisor, a hot fundable area, and a problem found along the way. Furieri gives me world-class ML-control training, an entrepreneurial mentor, and a network *regardless* of the exact topic. **Don't over-engineer the "perfect startup topic" now** — optimise for capability + fit + mentor; let the venture crystallise during the PhD (§11e).

---

## 9. The Oxford research-degree path: structure, duration & funding

### 9a. PRS → transfer → confirmation
Every research student starts as a **Probationer Research Student (PRS)**. **~End of year 1 (by the 4th term, max 6th)**, **Transfer of Status** decides **MSc by Research** ("worthwhile contribution") vs **DPhil** ("significant and substantial contribution"), assessed by two non-supervisor faculty + oral. DPhil then requires **Confirmation of Status** (~9 terms).

### 9b. The three degree shapes (clearing up the "1-year MSc" myth)
- **Taught MSc — ~1 year.** *This* is the 1-year master's students mean — no research project, no platform, no supervisor relationship, no DPhil path. ES barely offers taught MScs. **Not the target.**
- **MSc by Research — normally 2 years** in ES and Materials (thesis within 2, at most 3). A "1-year MSc by Research" is **not** an admission route here.
- **DPhil — 3–4 years** realistically (3 is the floor). *Not* "only 3."

### 9c. Funding reality (flips the naive logic)
- **The MSc by Research is rarely funded** — most studentships/scholarships target *doctoral* study. A 2-year MSc(R) usually means **self-funding at ~£33,370/year international fees + ~£17–25k/year living = well north of £100k over two years.**
- **The DPhil is where the funding is.** So the *longer* degree is the more financially accessible one.
- **Grades caveat:** supervisor backing carries *admission*; competitive scholarships (Clarendon, DTPs) weight grades — my weak spot. **Don't bank on those.** Target instead:
  - **Supervisor/grant-attached studentships** (the PI selects; fit + backing outweigh grades). Plays to Furieri/Mouthuy.
  - **External German funding** — DAAD, Studienstiftung, etc.
- **Caveat:** a DPhil studentship + early MSc exit can have funding-contract implications — known, non-catastrophic, but a bridge to be aware of.

### 9d. The resolution — apply to the DPhil, decide at transfer
Both routes start as PRS. So **apply to the DPhil**: (a) unlocks funding the MSc(R) can't access, and (b) still contains the **MSc by Research as a genuine early exit** if the startup pull wins. The **transfer point (~1 year in) is the real fork.**

### 9e. Timing & deadlines
- Both departments **closed for 2026-27, open for 2027-28** — fits the timeline (internship wraps ~Sept 2026).
- Because funding is the real hurdle, the **hard deadline is the December 2026 / January 2027 scholarship round.**
- Furieri recruits via the **DPhil in Engineering Science**, ~early-December deadline for October entry.

### 9f. PhD vs MSc — RESOLVED (stop re-litigating)
**Decision: apply to the funded DPhil. The self-funded MSc by Research as a *destination* is off the table.** Why the dilemma dissolves:
- **The MSc(R) is the *dominated* option.** It costs **~£100k out of pocket** (rarely funded), gives a **thinner foundation** (2 years, less depth, fewer publications, less IP), *and* saves only **~1.5 years**. Paying six figures for a weaker result, slightly faster, is a bad trade when optimising time *and* money toward a company.
- **Two corrections to common (lab) advice:** budget the DPhil at **3.5–4 years**, not "only 3" (3 is the floor); and the "1-year" option is a **taught MSc** — a different degree with no research, no platform, no supervisor relationship. The *research* MSc is 2 years. The 1-year idea is a mirage.
- **So the real choice is only: funded DPhil vs. skip a degree entirely** and go straight at a frontier company / founding.
- **You don't even decide that upfront.** Apply to the funded DPhil; at **transfer of status (~end of year 1)** either continue (if it's compounding) or **exit with an MSc by Research — earned *while paid*, not for £100k.** Applying to the DPhil buys the option value of both, with a real decision gate one year in (when I'll know if the research is working, Furieri is great, the venture is crystallising, DeepMind is calling). Applying ≠ locking into four years.
- **The one condition that actually decides it (self-assessment — Q12):** all of this assumes I genuinely want to *do the research*. If yes → the funded DPhil is clearly best. If I'm honestly lukewarm and just want to build fast → **don't do any degree**; a PhD I don't want is a miserable multi-year slog, funded or not. The deciding question isn't money or time — it's internal.

### Indicative 2-year shape (works as terminal MSc *or* DPhil years 1–2)
- **Year 1 (to transfer):** implement a **guaranteed-stable learning controller** for the shoulder bioreactor; validate **precise, programmable strain**; integrate a **real-time tissue readout**; close the loop. → clears MSc-R.
- **Year 2:** show **adaptive closed-loop control beats fixed scripts**; demonstrate guarantees under the developing plant / a learned new regime. → DPhil-scale if continuing; strong terminal MSc-R + startup IP if exiting.
- **Headline result:** *a provably-stable, RL-driven humanoid bioreactor that autonomously improves muscle function over scripted stimulation.*

---

## 10. Department & supervision strategy

### 10a. The advantage is attached to the project + people, NOT the department — three layers
- **Department** = where I'm registered / the parchment → credential-legibility lever (reason to prefer ES).
- **Project** = the humanoid bioreactor (my edge: built the robot; thesis = its control seed) — doesn't change with the department.
- **Supervision** = Furieri (ES primary) + Mouthuy (co). My Pierre-lab experience is an edge relative to *Mouthuy* — who stays on the team.
→ **In the ES route I keep the advantage *and* gain the label.** Change the container, keep the contents.

### 10b. The two routes

| Route | Home dept | Supervisor model | Credential | Admission odds | Notes |
|---|---|---|---|---|---|
| **ES-home** *(current lean)* | Engineering Science | **Furieri = primary**, Mouthuy = co | **Research degree in Engineering Science** — clean robotics label | Strong; Furieri decides, won via the *project + methods fit* | De-risked by the relationship + confirmed methods fit. Advantage preserved via Mouthuy co + platform-as-testbed. |
| **Materials-home** *(fallback)* | Materials | **Mouthuy = primary**, Furieri/ORI = co | Research degree in Materials | **Highest** — Mouthuy alone can wave me in | Label weaker for robotics but recoverable via thesis + publications. |

### 10c. Settled strategy
**Robotics-control core; humanoid as flagship testbed; Furieri (ES primary) + Mouthuy (co); apply to the DPhil in Engineering Science; decide MSc-vs-DPhil at transfer.** ES is the current lean; Materials the fallback if Furieri's robotics appetite doesn't firm up.

### 10d. The honest tradeoff
The advantage is **most potent for admission in the Materials route** (Mouthuy alone suffices). In ES it's marginally less of a slam-dunk on *admission* — but the **credential is better**. A good, conscious trade.

### 10e. Don't shop — bring your own project
With a warm supervisor I **bring and co-develop my own project**, not pick from a menu. The department follows from the project + supervisors; it is not a substitute for choosing them.
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

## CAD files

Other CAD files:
docs/chamber top and bottom (1).f3d

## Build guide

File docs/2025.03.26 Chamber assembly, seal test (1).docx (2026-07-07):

26th Mar 2025

Fixing the opposite end of the membrane and testing seal of the chamber system

Overview:

- A flexible membrane will be used to connect the 3D-printed parts of the bioreactor chamber
- The flexibility of the membrane ensures sufficient transmission of mechanical signals from the mechanical system
- Establishing a leak-proof connection between the 3D-printed parts and the membrane is essential
- In this experiment, the full chamber will be assembled with 3D printed parts on both sides connected by the flexible membrane
- The assembled chamber will then be analyzed for potential leakage by running water through the system
- The following setup is used to seal the 3D printed parts and membrane together

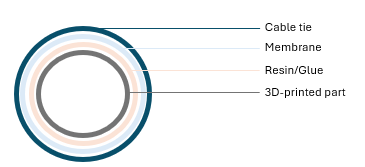
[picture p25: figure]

- An adhesive glue will be applied between the 3D-printed part and the membrane
- A cable tie will be used to cover the contact point between the 3D-printed part and the membrane to further tighten the seal
- Chamber: 3D-printed clear medical grade resin
- Adhesive: Polyurethane glue
- Flexible membrane: Permali Tuftane Thermoplastic Polyurethane film

Procedure:

Assembly

- Produce a flexible membrane sleeve with a diameter of 3.8cm
- Place the flexible membrane onto the 3D printed part
- Use a syringe and needle to add the adhesive glue between the printed part and the membrane
- Place a cable tie on top of the contact area of the membrane and printed part and tighten it
- Leave the glue to dry for 12 hours

Leak test

- All luer locks except one will be closed/sealed
- A large syringe will be filled with water and attached to the system
- The water will be run through the system creating pressure to identify potential points of leakage

Results:

Final chamber:

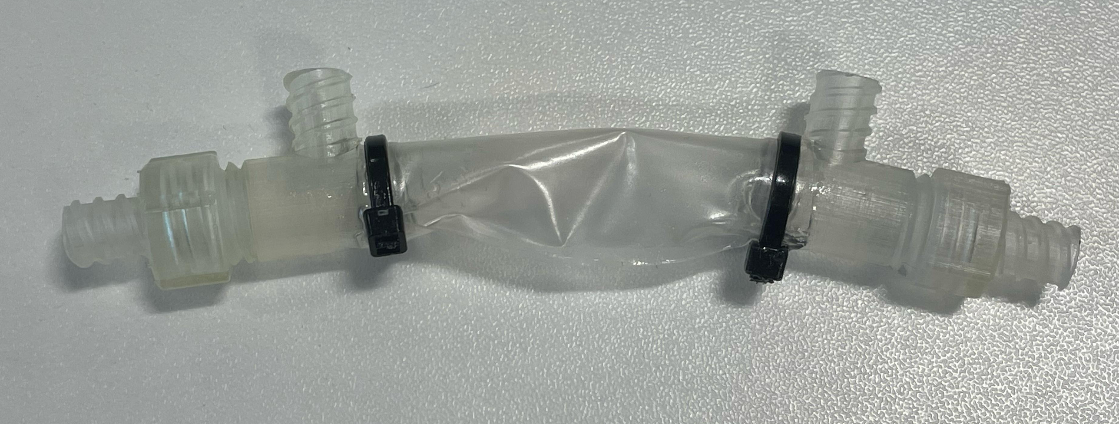
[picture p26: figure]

- Luer stops were used effectively for the ends, however, the side outlets/inlets could not be closed
- This could be due to residues of support structures from the printing process
- Blue tac was used as a temporary solution to seal the side outlets/inlets

Leak test setup:

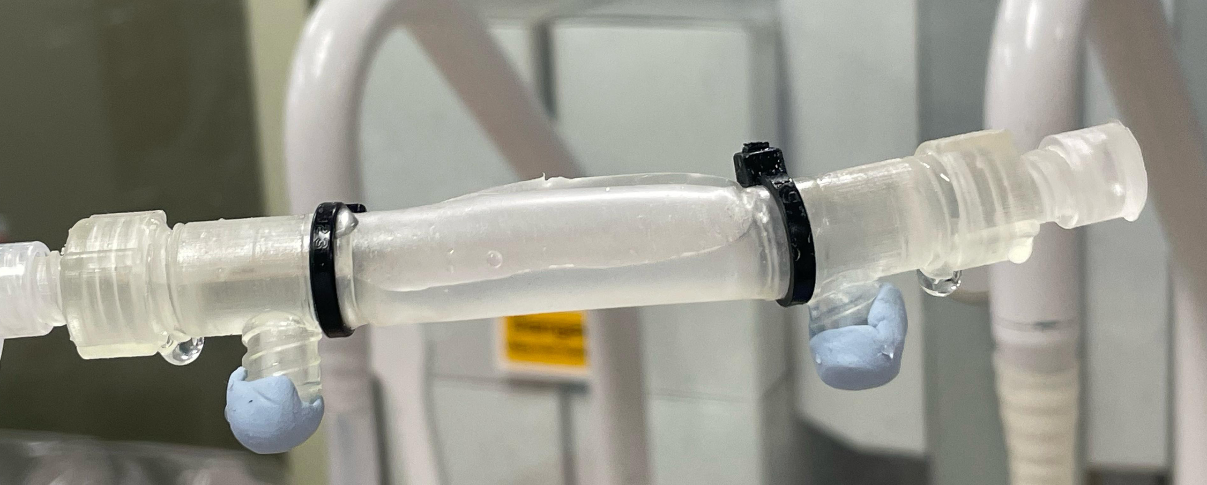
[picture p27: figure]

- Leakage was observed at the screwed parts on both sides
- Parafilm and tape were tested to seal the screwed parts
- The tape showed not to reduce leakage
- Parafilm showed to cause a reduction in leakage, however, some small drop formation was still observed
- Subsequently, parafilm in combination with vacuum grease was tested. This showed to seal the screwed parts with no observed leakage

Next steps:

- Test elastic rings instead of cable ties for assembly of the chamber
- Remove blockage inside side outlets/inlets and test the luer stop again
- Run leak test with luer stops on the side outlets/inlets
- Test polyurethane glue (instead of parafilm) to seal the screwed ends

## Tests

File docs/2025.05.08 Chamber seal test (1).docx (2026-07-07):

8th May 2025

Testing chamber sealing for leakage
- PTFE tape

Overview:

- A flexible membrane is used to connect the 3D-printed parts of the bioreactor chamber
- Establishing leak-proof connections between all parts of the assembled chamber is essential
- This is also important to maintain a sterile environment within the chamber, and potential points of leakage or entry of pathogens can be identified with a leak test
- In previous experiments,
  - Parafilm alone was insufficient to seal the chamber parts
  - Parafilm in combination with grease created a sufficient seal; however, the application of grease is not a feasible option
  - PTFE film applied on the outside of connecting pieces did not provide a good seal
- In this experiment,
  - PTFE film will be tested on the inside of connecting pieces
- The chamber will be tested for potential leakage by running water through the system under pressure

Procedure:

Leak test

- Apply the PTFE tape in-between connecting points (screwed parts, luer locks)
- Fill a large syringe with water and attach it to a luer lock on one end of the chamber
- Run the water through the system creating pressure to identify potential points of leakage

Results:

PTFE only:

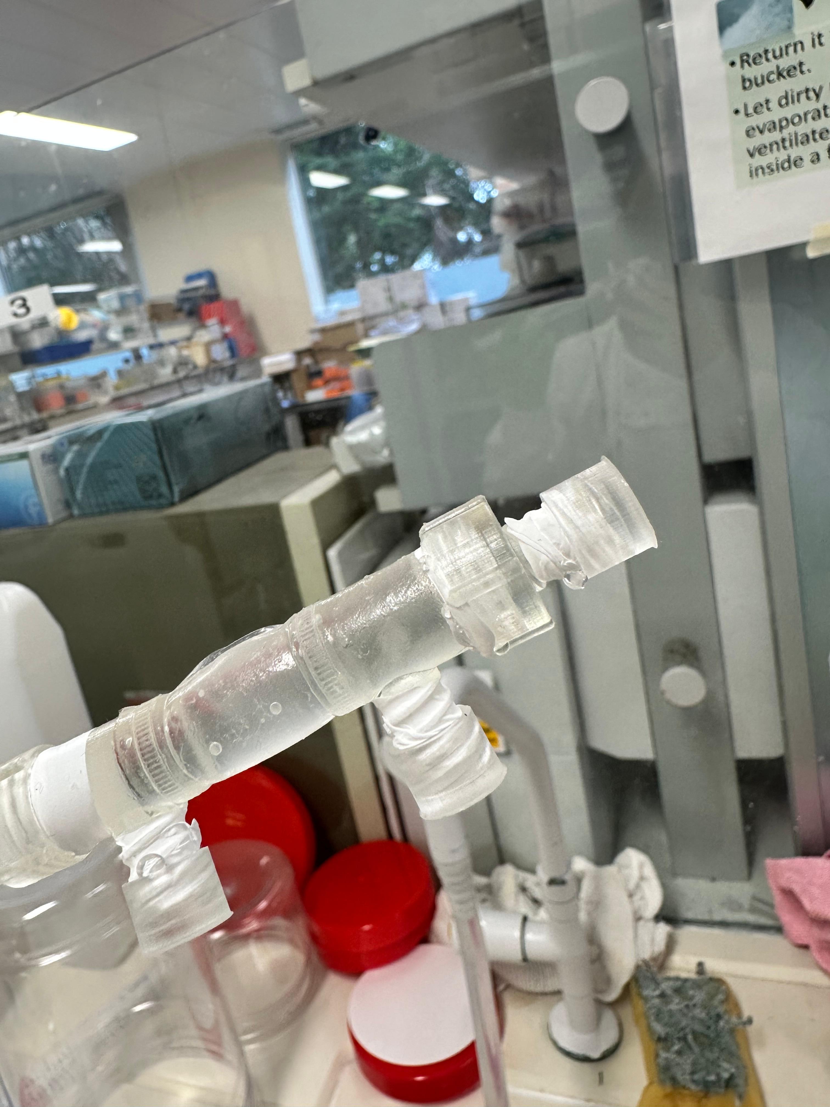
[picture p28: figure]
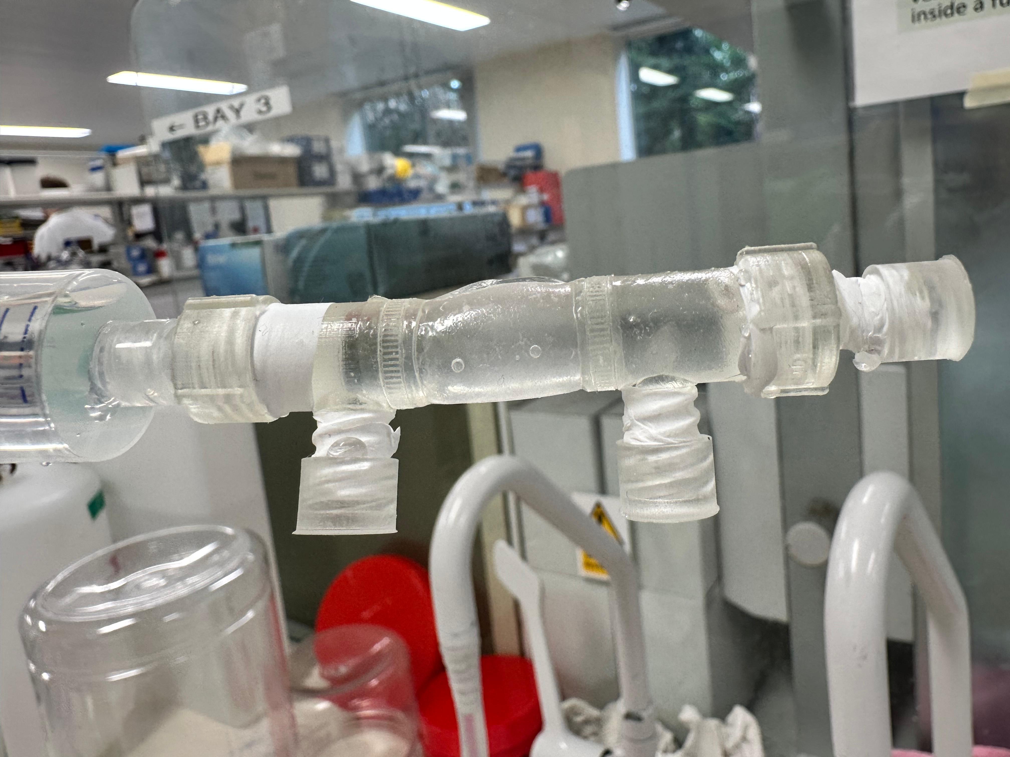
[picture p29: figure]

- Some leakage was observed despite the PTFE tape

PFTE plus parafilm:

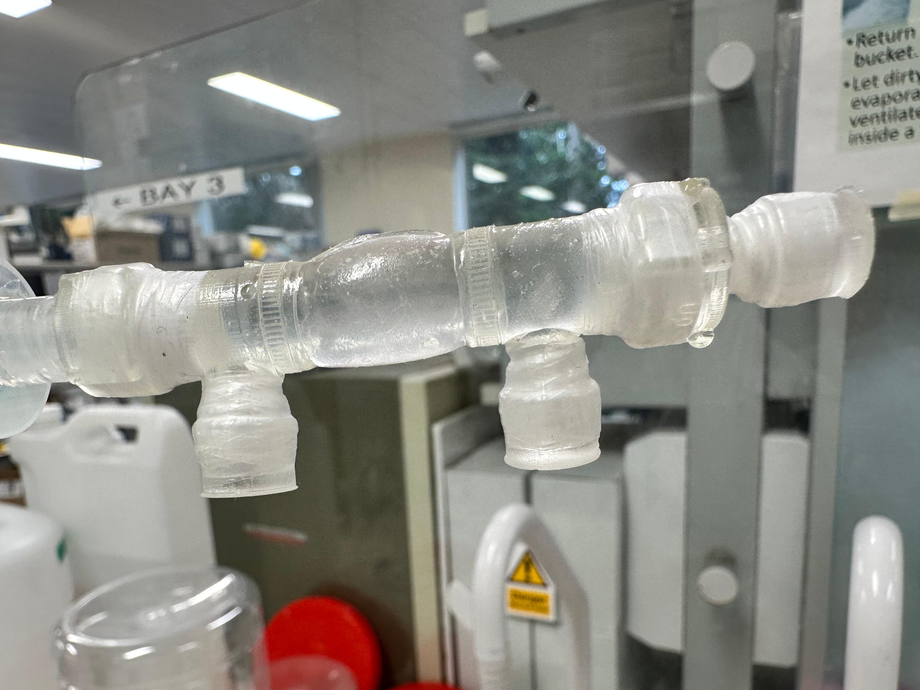
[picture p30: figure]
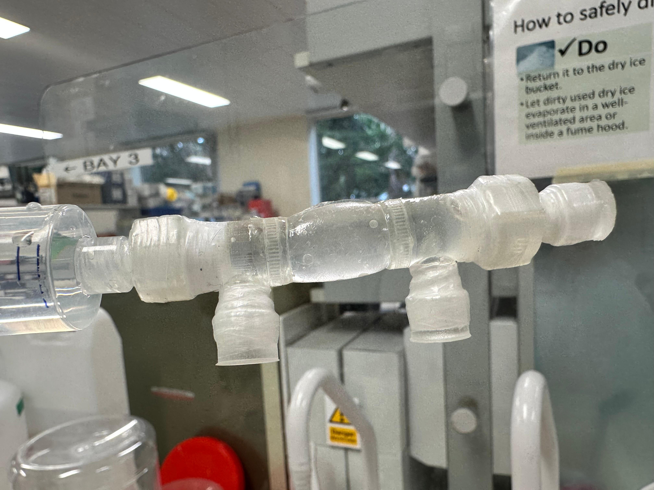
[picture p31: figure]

- With one and two layers of parafilm used in addition to the PTFE tape, leakage was still observed
- With three layers of parafilm in addition to the PTFE tape, the chamber appeared to be fully sealed, even under pressure

Next steps:

- The application of PTFE tape in addition to multiple layers of parafilm is rather unpractical
- Therefore, alternative options, such as glued on pieces, will be investigated

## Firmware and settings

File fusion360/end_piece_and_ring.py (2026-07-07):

# -*- coding: utf-8 -*-
#
# Soft hollow-fibre bioreactor chamber — ONE rigid END PIECE + its TIGHTENING RING.
# Fusion 360 script.  Paste into Scripts & Add-Ins -> "+" -> create a Python script,
# replace the generated file with this one, and Run.  Builds in the ACTIVE document.
#
# Architecture (one end piece, outboard -> inboard along +Z):
#   0  outboard face
#   1  AXIAL ICS port  (female Luer-lock 6% sealing taper)  ->
#   2  lumen-header cavity (dia = shell_bore)               ->
#   3  potting zone: plain through-bore (dia = shell_bore); fibres + PU form the plug later ->
#   4  90-degree ECS port (female Luer on a radial stub) tapping the bore ecs_inboard_offset
#      INBOARD of the potting zone (feeds the shell, never the lumen header)             ->
#   5  inboard SPIGOT (reduced OD, bore continues = shell_bore):
#        base->tip:  external THREADED BOSS | O-RING GROOVE | sealing BARB | CAPTURE GROOVE
#
# The two chamber ends are geometrically identical (one plumbed inlets, one outlets),
# so this single part serves both -> print two end pieces and two rings.
#
# Tightening ring: separate printed cap-nut. Internal thread on the boss, hard-stop
# shoulder, skirt over the cuff, internal capture lip, through-hole for cuff+membrane,
# and 6 external grip flats. Sits OUTSIDE the wetted path.
#
# NOTES / DECISIONS
#   * Doc check: Marie's transfer report gives post-stretch eHF ~198um OD / 89um lumen,
#     8 cm working length -> shell_bore=8 mm is ample. The assembly notes give the
#     silicone cuff sleeve as ~3.8 cm circumference (~12 mm ID) -> matches spigot_OD=12.
#     No document value contradicts the supplied defaults.
#   * Fusion's internal length unit is CENTIMETRES. Every length here is either a named
#     user parameter (mm) or built with ValueInput.createByString(...) -> no bare mm floats.
#   * The primary solids (body / boss / spigot / bores / stub / ring) are driven by
#     dimensions and offset planes bound to user parameters, so they update live when you
#     edit a parameter. The small revolved detail features (Luer tapers, grooves, barb) are
#     generated from the parameter values at build time; the script is idempotent (it
#     deletes and rebuilds the two components), so after changing a parameter just Run again.
#   * Threads use Fusion's modelled Thread feature where possible; if that proves
#     unreliable the boss/ring fall back to a smooth surface at the nominal major dia
#     (see "# TODO thread") and a warning is reported -- threads never block the build.

import adsk.core
import adsk.fusion
import math
import traceback

# ------------------------------------------------------------------ build switch
# use_luer=True  -> female Luer-lock ports (ISO 80369-7, 6% taper) on both circuits.
# use_luer=False -> hose barbs for silicone tubing of ID = tubing_id instead.
# (Boolean, so it is a Python switch, not a Fusion user parameter which must be numeric.)
USE_LUER = True


def run(context):
    ui = None
    try:
        app = adsk.core.Application.get()
        ui = app.userInterface

        design = adsk.fusion.Design.cast(app.activeProduct)
        if not design:
            ui.messageBox('No active Fusion design. Open a Design and run again.')
            return
        # Keep it parametric.
        design.designType = adsk.fusion.DesignTypes.ParametricDesignType

        root = design.rootComponent
        up = design.userParameters
        VI = adsk.core.ValueInput
        FO = adsk.fusion.FeatureOperations

        warnings = []
        created_params = []

        # -------------------------------------------------------------- parameters
        def add_param(name, expr, unit='mm', comment=''):
            """Create (or, on re-run, update) a user parameter. Everything tunable here."""
            p = up.itemByName(name)
            if p:
                p.expression = expr
            else:
                p = up.add(name, VI.createByString(expr), unit, comment)
            if name not in created_params:
                created_params.append(name)
            return p

        # --- BRIEF DEFAULTS (base) ------------------------------------------------
        add_param('shell_bore',        '8',    'mm', 'main bore; fibre bundle + potting')
        add_param('body_wall',         '3',    'mm', 'rigid body wall thickness')
        add_param('spigot_wall',       '2',    'mm', 'spigot tube wall thickness')
        add_param('lumen_header_depth', '4',   'mm', 'ICS header counterbore depth')
        add_param('potting_length',    '6',    'mm', 'axial length of the potting plug zone')
        add_param('ecs_inboard_offset', '5',   'mm', 'ECS tap sits this far INBOARD of potting')
        add_param('spigot_engagement', '12',   'mm', 'reduced-OD spigot length the cuff sits on')
        add_param('boss_thread_major', '20',   'mm', 'external boss thread major dia')
        add_param('thread_pitch',      '2',    'mm', 'boss/ring thread pitch')
        add_param('boss_length',       '8',    'mm', 'threaded boss axial length')
        add_param('ring_wall',         '3',    'mm', 'tightening-ring wall thickness')
        add_param('oring_cs',          '2',    'mm', 'O-ring cross-section dia')
        add_param('barb_height',       '0.5',  'mm', 'sealing barb radial height')
        add_param('capture_groove',    '1.5',  'mm', 'capture groove (square) side')
        add_param('ecs_stub_length',   '10',   'mm', 'radial ECS stub length beyond body OD')
        add_param('fillet_r',          '1',    'mm', 'fillet radius on step transitions')
        add_param('thread_clearance',  '0.35', 'mm', 'radial thread clearance (ring vs boss)')
        add_param('slip_clearance',    '0.2',  'mm', 'radial slip fit clearance')
        add_param('luer_mouth_ID',     '4.0',  'mm', 'female Luer mouth ID (ISO 80369-7)')
        add_param('luer_taper_length', '7.5',  'mm', 'female Luer taper engagement length')
        add_param('tubing_id',         '1.6',  'mm', 'barb fallback: silicone tubing ID')

        # --- ASSUMPTIONS (not fixed by the brief/docs; tune to your cuff & fittings) ---
        add_param('cuff_wall',      '1.5', 'mm', 'ASSUMED silicone cuff wall thickness')
        add_param('cuff_flange',    '1.5', 'mm', 'ASSUMED cuff mouth-flange radial height')
        add_param('ecs_stub_od',    '8.0', 'mm', 'ASSUMED ECS stub OD (houses female Luer)')
        add_param('ecs_channel_dia', '2.0', 'mm', 'ASSUMED ECS connecting channel bore')
        add_param('barb_width',     '1.2', 'mm', 'ASSUMED sealing-barb axial width')
        add_param('ring_lip_length', '2.0', 'mm', 'ASSUMED ring capture-lip length')
        add_param('ring_grip_depth', '0.6', 'mm', 'ASSUMED grip flat depth')
        add_param('barb_boss_len',  '6.0', 'mm', 'ASSUMED hose-barb nipple length (use_luer=False)')
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

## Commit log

2026-07-07 uploaded docs
    [chamber top and bottom (1).f3d]
2026-07-07 Add parametric Fusion 360 script for end piece + tightening ring (#1)
    * Add parametric Fusion 360 script for end piece + tightening ring
    Builds one rigid end piece (axial ICS Luer port -> lumen header -> potting
    through-bore -> 90-degree ECS Luer port inboard of potting -> spigot with
    threaded boss, O-ring groove, sealing barb and capture groove) plus its
    tightening cap-nut ring, both as separate printable components.
    All dimensions are Fusion user parameters (mm); primary solids are driven by
    parameter-bound dimensions and offset planes. Threads use the modelled Thread
    feature with a smooth-boss fallback so they never block the build. Includes a
    hose-barb fallback (USE_LUER=False) and an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
    [end_piece_and_ring.py]
2026-07-07 Handle Part Design documents (single-component fallback) (#2)
    Fusion's newer default 'Part Design' documents allow only one component, so
    addNewComponent for the second component raised a RuntimeError before any
    geometry was built. Build both parts as separate bodies in the root component
    when component creation is rejected, and report it in the summary with a note
    to use an Assembly Design document for separate, individually printable
    components. Also clean up prior bodies on re-run in that mode.
    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
2026-07-07 Fix ECS Luer revolve: avoid ConstructionAxes (environment error) (#3)
    ConstructionAxes.add raised RuntimeError 'Environment is not supported' when
    creating the radial axis for the ECS Luer socket revolve in some Fusion
    document environments. Revolve that socket about the profile's own base edge
    (a sketch line on the z=z_ecs line) instead, which every environment supports.
    No geometry change; the socket is identical.
    Claude-Session: https://claude.ai/code/session_016c1XvbsnHBzHUG9WbSDaJu
    [end_piece_and_ring.py]
